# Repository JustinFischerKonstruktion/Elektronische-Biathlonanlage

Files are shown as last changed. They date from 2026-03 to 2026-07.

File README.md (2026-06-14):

# Elektronische Biathlonanlage

## Allgemeines
Das Projekt **"Elektronische Biathlonanlage"** ist ein Umbau für Luftgewehr-Biathlonanlagen. Dieser sorgt dafür, dass die Scheiben nach 5 Treffern oder nach einer eingestellten Zeit ohne Treffer automatisch "gezogen" werden. Zur Datenerfassung werden die einzelnen Treffer zusammen mit der Position innerhalb eines **ESP-NOW Netzwerkes** versendet.

Das System bringt einige Vorteile mit sich: Durch das Fehlen der klassischen Seile der Biathlonanlagen ist kein Auf- und Abwickeln im Training mehr nötig – einfach Strom einschalten und lostrainieren! Auch die Gefahr, dass sich die Seile verknoten oder spannen, wodurch das Fallen der Scheiben verhindert wird, sinkt deutlich. Durch das automatische „Ziehen“ der Anlagen ist ein reibungsloser Ablauf des Trainings möglich. Keiner kann vergessen, die Scheibe zu ziehen, und es kann kein „unvollständiges Ziehen“ geben. Durch das offene System können Trainingsdaten erfasst werden; hier ist für die Zukunft eine Weiterentwicklung mit einer Laufzeitmessung geplant (siehe Zukunftsvision). Durch die zerstörungsfreie Anbringung der 3D-Druckteile geht die Anlage nicht kaputt, die Garantie des Anlagenherstellers wird also nicht verletzt. Die Platine kann sowohl an der Anlage direkt als auch am Stand angebracht werden, somit kann die Anlage flexibel an verschiedenen Standorten eingesetzt werden. Das wasserabweisende und größtenteils auch wasserfeste Design ist auf den Außeneinsatz angepasst.

Der Schützenverein Wolfartsweiler ([sv-wolfartsweiler.de](https://www.sv-wolfartsweiler.de)) hat seit über einem Jahr 8 umgebaute Anlagen im Betrieb. Pro Anlage kostete uns der Umbau ca. 210 €. Pro Anlage kann man mit ca. 2 Arbeitsstunden für die Installation rechnen, zusätzlich zur Installation von Kabeln im Schießstand. Außerdem testet der Schützenverein aktuell einen Prototypen zur autonomen Laufzeiterfassung und Laufzeitauswertung.

Mit dem Wettbewerb NMH Makes Heroes ([nmh-makes-heroes.nmh.de](https://nmh-makes-heroes.nmh.de)) unterstützte mich die Firma NMH ([nmh.de](https://www.nmh.de)) mit einer Fördersumme und technischer Beratung. Während der kurzen Wettbewerbszeit (ca. 6 Wochen) entstand aus einem Prototypen ein fertiges, einsatzfähiges System, welches ich bei allen 8 Anlagen installieren konnte. Vielen Dank an dieser Stelle an NMH!

Wenn Sie mein Projekt interessiert und Sie sich für die Zukunft des Projektes interessieren, können Sie sich gerne die Zukunftsvision anschauen; hier werden mögliche Weiterentwicklungen aufgezeigt. Wenn Sie mich unterstützen wollen, können Sie das gerne über gofundme machen: https://gofund.me/d172d4579 . Sollten Sie Anregungen, Fehler oder Wünsche haben, können Sie hier Issues erstellen oder einfach eine Diskussion starten. Auch auf Instagram können Sie gerne Kontakt zu mir aufnehmen: [@justin_fischer_konstruktion](https://www.instagram.com/justin_fischer_konstruktion/)

## Hardware

Die Automatisierung der Anlage erfolgt mithilfe von Endschaltern und einem **12V DC Motor**, gesteuert von einem **ESP32-D1 mini** auf einer eigens entworfenen Platine. Hier werden die Endschalter so verkabelt, dass die Scheibenposition im Programm (Scheibe 1–5) mit der mechanischen Position übereinstimmt.

Die 3D-gedruckten Komponenten werden zerstörungsfrei an den bestehenden Anlagen angebracht.
**Getestete Anlagen:** Rika und Hora
**Link zu den 3D-Modellen inkl. Druckeinstellungen (MakerWorld):**
*(STEP-Dateien findet ihr hier auf GitHub)*

**Hora:**
* Gesamte Anlage: https://makerworld.com/de/models/2599343-umbau-hora-anlage-gesamt#profileId-2868269
* Motorhalter: https://makerworld.com/de/models/2634566-motorgehause-hora#profileId-2909867
* Endschalterhalter: https://makerworld.com/de/models/2634540-endschalterhalterung-hora#profileId-2909835
* Halter / Halter mit Kabel: https://makerworld.com/de/models/2634652-platinengehausehalter-hora#profileId-2909964

**Rika:**
* Gesamte Anlage: https://makerworld.com/de/models/2634761-umbau-rika-anlage-gesamt#profileId-2910064
* Motorhalter: https://makerworld.com/de/models/2634928-motorgehause-rika#profileId-2910264
* Endschalterhalter: https://makerworld.com/de/models/2634916-endschalterhalterung-rika#profileId-2910247
* Platinenhalter:https://makerworld.com/de/models/2634963-platinenhalterung-rika#profileId-2910308

**Zubehör für beide Typen:**
* Platinenhalter außen: https://makerworld.com/de/models/2635003-platinengehaussehalterung-aussen#profileId-2910358
* Scheibe: https://makerworld.com/de/models/2635039-scheibe#profileId-2910395
* Adapter Platine zu Gehäuse: https://makerworld.com/de/models/2635074-adapter-platine#profileId-2910440

**Update(14.06.26):** Bei der Scheibe wurde eine zusätzliche Fixierung durch eine M3 Schraube vorgesehen.

Zur Einhaltung der Schießstandrichtlinien wurde eine Verkleidung aus Blech an dem Motorhalter angebracht. Diese wurde bei Blexon bestellt. Die entsprechende **STEP-Datei des Blechs** findet ihr ebenfalls hier bei GitHub. Wir haben ein 2 mm Edelstahlblech verwendet, um den Schießstandrichtlinien gerecht zu werden und um Rost und Abnutzung vorzubeugen.

**Blexon Link:** [blexon.com](https://blexon.com)

---

## Verkabelung

Zur Verkabelung der Anlage wurde eine selbst entworfene Platine angefertigt.

<p align="center">
  Verkabelung_Steckplatine
  <br>
  <em style="color: grey;">Abbildung 1: Schaltlogik (unmaßstäblich, erstellt mit Fritzing)</em>
</p>

### Überblick der Verkabelung:

* Alle Endschalter sind über den **COM-Anschluss** mit Ground (GND) verbunden.
* Das Relaismodul wird mit **5V** betrieben und verbindet den Motor über den **Normally Open (NO)** Anschluss mit +12V.
* Der Informationsanschluss des Relaismoduls wird mit **Pin 25** des ESP32 verbunden.
* Der Endschalter beim Motor wird über den **NO-Anschluss** mit **Pin 16** des ESP32 verbunden.

Die Endschalter der Klappen werden über die **NO-Anschlüsse** an folgende Pins angeschlossen:
* Klappe 1: **Pin 23**
* Klappe 2: **Pin 5**
* Klappe 3: **Pin 26**
* Klappe 4: **Pin 18**
* Klappe 5: **Pin 19**

**Meine Platine bei OSHWLab:** https://oshwlab.com/justin.fischer.konstruktion/project_apwkcymk

---

### Der Master

Der Master verfügt über folgende Anbauteile:

**Real time clock (RTC):**
* SCL an **Pin 22**
* SDA an **Pin 21**

**JDY-31 Bluetooth-serielles Modul:**
* RX an **Pin 16**
* TX an **Pin 17**

---

### Stücklisten

#### Stückliste für eine Anlage:

| Bezeichnung | Stückzahl pro Anlage | Link |
| :--- | :---: | :--- |
| **3D-Gedruckte Teile** | | |
| Endschalterhalter (2 Varianten) | 5 | |
| Motorgehäuse | 1 | |
| Scheibe | 1 | |
| Gehäusehalterungen | 1 | |
| Gehäusehalterungen (optional) | (1) | |
| **Zukaufteile** | | |
| Edelstahlbleche | 1 | |
| ESP32 D1 Mini | 1 | [Amazon](https://www.amazon.de/dp/B0DHY5C3Q3) |
| Step Down Converter | 1 | [Amazon](https://www.amazon.de/dp/B0B92ZDK6T) |
| 12V DC Motor | 1 | [Amazon](https://www.amazon.de/dp/B0D9JTQWVB) |
| Platine (optional) | (1) | siehe unten |
| Gehäuse für Platine | (1) | [Amazon](https://www.amazon.de/dp/B0747RGBFF) |
| Endschalter für Motor | 5 | [Amazon](https://www.amazon.de/dp/B0DX27MVWB) |
| Endschalter für Klappen | 1 | [Reichelt](https://www.reichelt.de/de/de/shop/produkt/snap-action-mikroschalter_1x_um_rollenhebel-191380) |
| Kabel (Stromversorgung) | 1 | [Amazon](https://www.amazon.de/dp/B07DPND6NG) |
| Kugellager | 1 | [Amazon](https://www.amazon.de/dp/B0CL4ZN6BV) |
| Schrauben M2x10 | 2 | [Amazon](https://www.amazon.de/dp/B015A3ISUA) |
| Schrauben M2x12 | 10 | [Amazon](https://www.amazon.de/dp/B0DMSP42ZG?ref_=ppx_hzsearch_conn_dt_b_fed_asin_title_6) |
| Schrauben M3x8 | 12 | [Amazon](https://www.amazon.de/dp/B073ZY19VS) |
| Schrauben M3x25 | 2 | [Amazon](https://www.amazon.de/dp/B0DHKQNZ2C?ref_=ppx_hzsearch_conn_dt_b_fed_asin_title_5&th=1) |
| Schrauben M5x10 | 2 | [Amazon](https://www.amazon.de/dp/B015A3ISUA) |
| Selbstschneidende Schrauben | 4 | [Amazon](https://www.amazon.de/dp/B0D9JTQWVB) |
| Einschmelzmutter M3 | 4 (8 für Hora) | [Amazon](https://www.amazon.de/dp/B0CRHMB248) |
| Mutter M3 | 2 (6 für Rika) | bei Schrauben dabei |
| Kabeldurchführungen | 8 | [Amazon](https://www.amazon.de/dp/B0CXPSG55G) |
| Radialwellendichtring (opt.) | (1) | [Amazon](https://www.amazon.de/dp/B0DVJ32JPS) |

#### Stückliste des Masters:

| Bezeichnung | Stückzahl | Link |
| :--- | :---: | :--- |
| ESP32 D1 Mini | 1 | [Amazon](https://www.amazon.de/dp/B0DHY5C3Q3) |
| Bluetooth Modul | 1 | [Amazon](https://www.amazon.de/dp/B0FFZ43YCC) |
| Real time Clock Modul | 1 | [Amazon](https://www.amazon.de/dp/B01H5NAFUY) |
| Gehäuse für ESP32 | (1) | [Amazon](https://www.amazon.de/dp/B0747RGBFF) |
| Lötplatine | (1) | [Amazon](https://www.amazon.de/dp/B07DK2S1XG) |

**Sonstige Zukaufteile:**
* Kabel: [Amazon](https://www.amazon.de/dp/B07DK2S1XG)
* Verteilerdosen: [Amazon](https://www.amazon.de/dp/B09D3XP1Z1)
* Solarmodul inkl. Akku: [Amazon](https://www.amazon.de/dp/B09D3XP1Z1)
* 12V-Netzteil: [Amazon](https://www.amazon.de/dp/B07GFFG1BQ)
* DC-Backup Schaltmodul: [Amazon](https://www.amazon.de/dp/B07B4D73K9)
* Dichtungsstreifen: [Amazon](https://www.amazon.de/dp/B0CWNCHX7T)

---

## Software

Die Software der Anlagen sowie des Masters wurde mit der **Arduino IDE** geschrieben. Ihr findet die `.ino`-Dateien zum Download im Ordner `Software`.

Bei Inbetriebnahme müsst ihr die MAC-Adresse eures Masters herausfinden und notieren. In den Skripten der Anlagen müssen folgende drei Variablen ganz oben im Code angepasst werden:

1. **Anlage:** Die Nummer eurer Anlage (von oben nach unten, dann von links nach rechts). Beispiel: Stehende Anlage links = Nr. 1; liegende Anlage = Nr. 2; zweite stehende Anlage von links = Nr. 3 usw.
2. **uint8_t receiverAddress[]:** Die MAC-Adresse eures Masters.
3. **Variable `zeit`:** Hier wird die Zeit eingestellt, nach der die Anlage automatisch zieht. Standardmäßig nutzen wir für liegende Anlagen 10 Sekunden (`zeit=10000`) und für stehende Anlagen 20 Sekunden (`zeit=20000`). Die Angabe erfolgt in Millisekunden.

### Handy-App

Hier auf GitHub findet ihr im Ordner `Software` die Biathlon-App sowohl als APK zum Installieren auf Android-Handys als auch die AIA-Datei zum Öffnen in App Inventor für die Anpassung an eure Bedürfnisse. Hierfür braucht ihr einen Account beim MIT App Inventor.
App Inventor: [appinventor.mit.edu](https://appinventor.mit.edu)

<p align="center">
  App Startseite
  <br>
  <em style="color: grey;">Abbildung 2: Handy App Startseite</em>
</p>

Auf der Startseite der App könnt ihr links oben die Seiten wechseln. Mit dem Button links neben der Mitte könnt ihr verfügbare Bluetooth-Geräte abfragen und euch verbinden. Danach werden euch die Treffer der Anlagen angezeigt. Mit den Schiebereglern wechselt ihr den Modus, mit den Reset-Knöpfen löst ihr den Ziehvorgang manuell aus (für alle Anlagen gleichzeitig oder einzeln).

<p align="center">
  App Einstellungen
  <br>
  <em style="color: grey;">Abbildung 3: Handy App Einstellungsseite</em>
</p>

Auf der Einstellungsseite könnt ihr eigene Zeiten für die Modi eingeben und per Senden-Button an den Master übertragen.

<p align="center">
  App Ergebnisse
  <br>
  <em style="color: grey;">Abbildung 4: Handy App Ergebnisseite</em>
</p>

Hier könnt ihr eine Liste der letzten Ergebnisse abfragen. Da die Übertragung via Bluetooth Zeit benötigt, ist diese Funktion bei begrenzter Leistung nicht immer zu 100 % zuverlässig.

---

## Netzwerk

<p align="center">
  Netzwerkaufbau
  <br>
  <em style="color: grey;">Abbildung 5: Netzwerkaufbau (erstellt mit Inkscape)</em>
</p>

Das Netzwerk besteht aus einem Master und bis zu 20 Slaves (bedingt durch die ESP-NOW Einschränkung). Die Anlagen fungieren als Slaves, der Master als eigenständige Zentrale. Wir haben unseren Master aktuell in der Nähe der Schützen platziert; der Abstand zu den Anlagen beträgt 10 m. Auf diese Distanz haben wir die Anlagen getestet und bisher keine Probleme festgestellt.

Folgende Variablen werden intern für Befehle und Daten genutzt:
* `hits`: Anzahl der Treffer
* `position`: Position des Treffers 1–5 (6 für Reset der Anzeige)
* `Anlage`: Nummer der sendenden Anlage
* `reset`: 0–n (Nummer der zu ziehenden Anlage; 0 = alle)
* `target`: 0–n (Wechsel in den Target-Modus; 0 = alle)
* `normal`: 0–n (Wechsel in den Magazin-Modus; 0 = alle)
* `customtarget`: Eigene Zeiteinstellung für den Targetmodus (in Sekunden)
* `customnormal`: Eigene Zeiteinstellung für den Magazinmodus (in Sekunden)

Wir haben das Netzwerk erfolgreich mit einem Master und 8 Slaves getestet und sind sehr zufrieden. Der Master verbindet sich per Bluetooth mit dem Handy; Daten und Befehle werden im Textformat gesendet und von der Android-App (erstellt mit **MIT App Inventor**) verarbeitet.

---

## Referenzen

Video, das die aktuellen Probleme von Seilzuganlagen aufzeigt:
<p align="center">
  <a href="https://youtu.be/Kdan_EM31K0">
    Video Thumbnail
    <br>
  <b>Video: Probleme der aktuellen Seilzuganlagen</b>
  </a>
<p align="center">
  <a href="https://youtu.be/Kdan_EM31K0](https://youtu.be/JK2AczdJDU0">
    
    <br>
  <b>Video: Trailer Projekt</b>
  </a>
</p>












## Haftungsausschluss (Disclaimer)

**Die Nutzung dieser Anleitung, der Software und der Hardware-Designs erfolgt auf eigene Gefahr.**

* **Keine Garantie:** Dieses Projekt wird "wie besehen" (as-is) zur Verfügung gestellt. Ich übernehme keine Garantie für die Funktion, Vollständigkeit oder Richtigkeit der bereitgestellten Informationen.
* **Haftungsausschluss:** Ich hafte nicht für Schäden an Hardware (z. B. Kurzschlüsse, defekte Motoren), Verletzungen oder sonstige Folgeschäden, die durch den Nachbau oder Betrieb dieser Anlage entstehen.
* **Eigenverantwortung:** Der Nutzer ist selbst dafür verantwortlich, dass der Umbau den geltenden Sicherheitsregeln und Schießstandrichtlinien entspricht.

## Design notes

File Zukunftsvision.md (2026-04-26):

# Zukunftsvision – Die Elektronische Biathlonanlage 2.0

Im Verein nutzen wir aktuell seit knapp einem Jahr acht aufgerüstete Biathlonanlagen und sind sehr zufrieden. Daher erfolgt nun auch die Veröffentlichung als Open-Source-Projekt.

Der aktuelle Aufbau ist jedoch recht zeitintensiv (ca. 2 Stunden pro Anlage) und benötigt Fachkenntnisse im Löten, Programmieren und 3D-Drucken. Nicht jeder Verein hat jemanden, der diese Fähigkeiten besitzt und gewillt ist, die Zeit dafür zu opfern. Daher möchte ich den Umbausatz zu einem echten „Plug-and-Play“-System weiterentwickeln.

#### Geplante Hardware-Änderungen:
* **Steckverbindungen:** Umstieg auf genormte Kabel mit M8- oder M12-Schraubverbindungen.
* **Sensorik:** Umstieg auf Induktivsensoren für die Treffererfassung (ebenfalls mit Standard-M12-Verbindung).
* **Antrieb:** Umstieg auf Servomotoren, um zusätzliche Endschalter zu vermeiden.
* **Platinen-Design:** * Eigene Platine speziell für Sensoren.
    * Neue Steuerplatine.
    * Neue Platine für die Stromversorgung mit Schaltlogik für den kombinierten Betrieb von Solar und Netzteil.
* **Kommunikation:** Anschluss eines M8- oder M12-Ethernet-Kabels ermöglichen, um eine reibungslose Kommunikation auch bei vielen Anlagen zu gewährleisten.
* **Mechanik:** Neue Halterungen für Sensoren, Platinen und Motoren sowie die Anpassung an weitere Anlagentypen.
* **Fertigung:** 3D-Druckteile per Link bestellbar machen (für Vereine ohne eigenen 3D-Drucker).

#### Begleitende Inhalte:
* YouTube-Tutorials für den Aufbau, die Software-Installation und die Bedienung der App.
* Eine YouTube-Entscheidungshilfe für interessierte Vereine.
* Eventuell eine eigene Projektwebsite sowie ein Discord-Kanal zur direkten Kommunikation.

### Kosten der Weiterentwicklung
Diese Entwicklung benötigt Zeit und finanziellen Einsatz. Die geplanten Entwicklungskosten belaufen sich auf:

| Teil | Preis |
| :--- | ---: |
| Testanlage leihen/kaufen | 350,00 € |
| Neue Steuerplatine | 25,00 € |
| Neue Sensorplatine | 30,00 € |
| Neue Stromverteilungsplatine | 20,00 € |
| Servomotor | 20,00 € |
| Induktivsensoren (5 Stück) | 70,00 € |
| 3D-Druckteile (Zukauf testen) | 120,00 € |
| Filament (Testdrucke) | 40,00 € |
| Kabel und Schrauben | 50,00 € |
| Netzgerät | 15,00 € |
| ESP32 D1 Mini (2x) | 30,00 € |
| Sonstige Teile | 30,00 € |
| **Gesamt** | **800,00 €** |

Ziel ist eine Plug-and-Play-Lösung, die einfach und schnell installiert werden kann. Die Kosten pro Umbausatz werden sich schätzungsweise auf ca. 250 € bis 350 € belaufen (abhängig von Stückzahl und Ausführung).

### Laufzeiterfassung
Aktuell arbeite ich zudem an einem Prototypen zur Laufzeiterfassung. Dieser ist momentan über ein einfaches NFC-Zeitnahmesystem umgesetzt, soll aber in naher Zukunft auf Kameratechnik umgestellt werden. Mithilfe von Google Sheets und App Script werden die Daten erfasst, sortiert und für jeden Athleten eine individuelle Übersicht erstellt. Da der erste Prototyp derzeit ausgiebig getestet wird, gibt es hier noch keine konkreten Kostenpläne; die Schätzung für das Gesamtsystem liegt bei ca. 500 €.

Sollten Ihnen diese Ideen gefallen, können Sie mich gerne bei der Umsetzung unterstützen. Bei gofundme sammle ich die 800€ für die Weiterentwicklung: https://gofund.me/d172d4579

Vielen Dank für Ihr Interesse und Ihre Unterstützung!

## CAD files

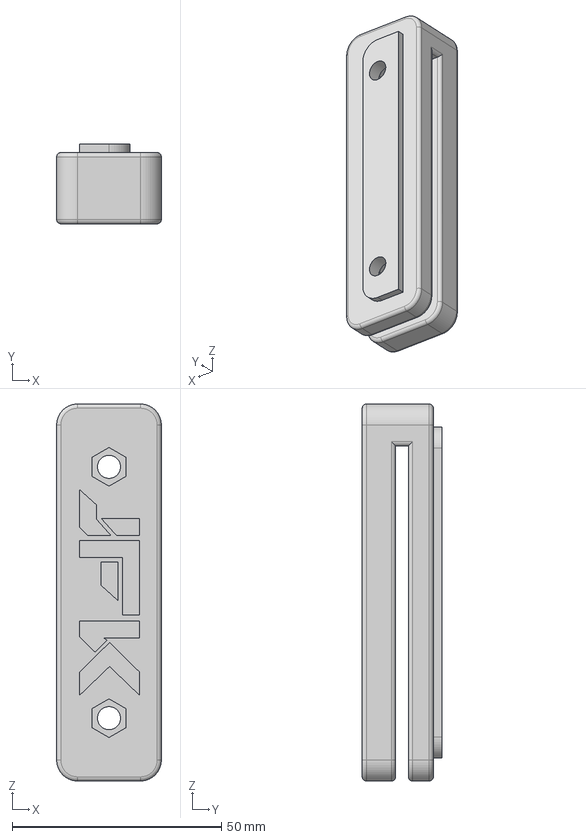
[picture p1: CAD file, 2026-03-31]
3D-Dateien/Hora/Halter Anlage 1.step
25.0 x 19.0 x 90.0 mm

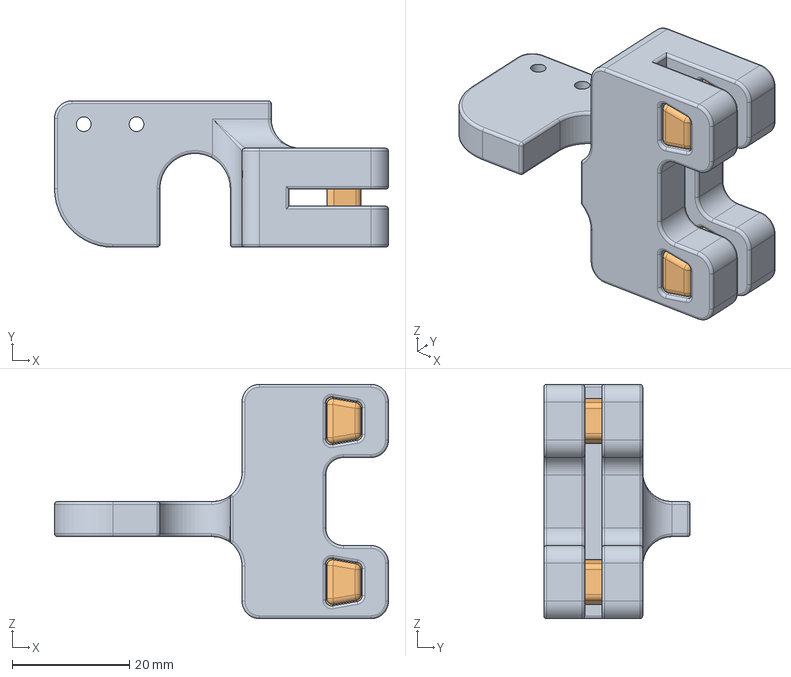
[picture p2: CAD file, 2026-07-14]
3D-Dateien/Rika/Endschalter mit Rolle.step
57.0 x 25.0 x 40.0 mm

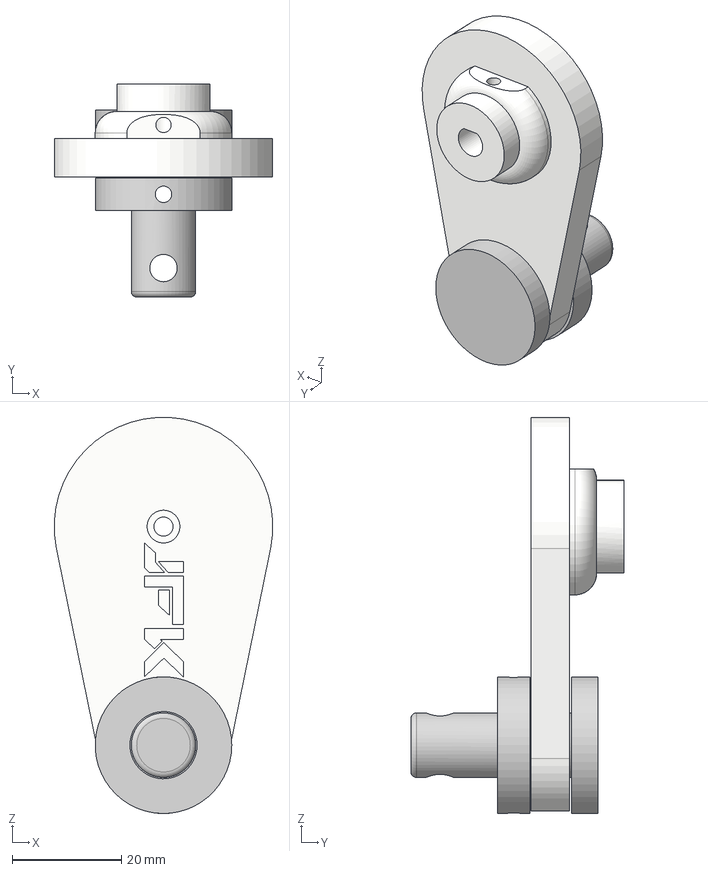
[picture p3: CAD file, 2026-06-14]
3D-Dateien/Zubehör für alle Typen/Scheibe neu.step
40.0 x 39.0 x 72.5 mm
Komponente1
Komponente2
Komponente4

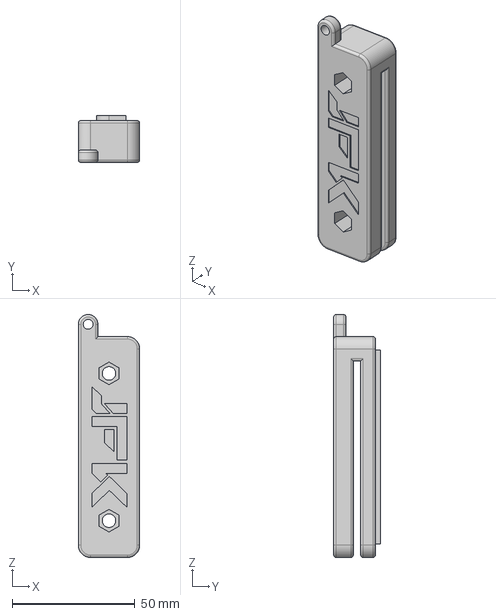
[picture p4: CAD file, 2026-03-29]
3D-Dateien/Hora/Halter Anlage 1mit kabel.step
25.0 x 19.0 x 99.0 mm

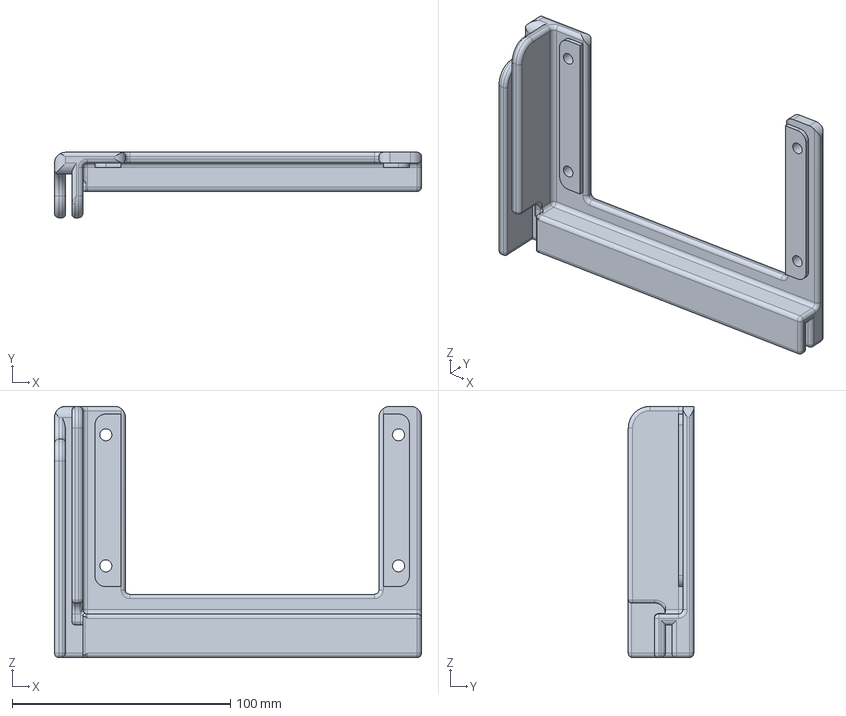
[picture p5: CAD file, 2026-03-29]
3D-Dateien/Rika/Halter Platine.step
168.0 x 30.0 x 115.0 mm

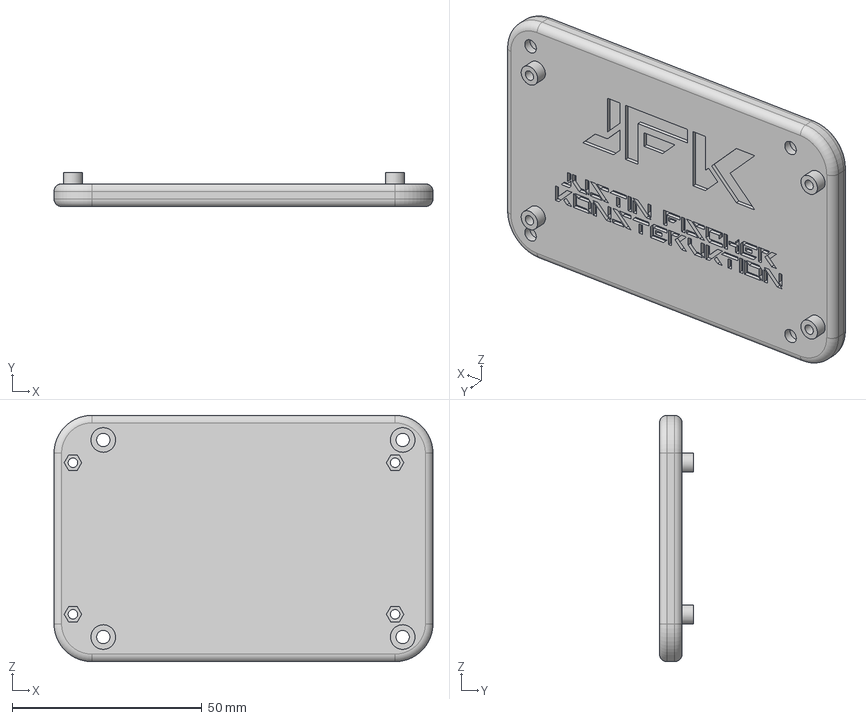
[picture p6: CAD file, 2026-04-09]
3D-Dateien/Zubehör für alle Typen/Adapter Platine v8.step
100.0 x 9.00 x 65.0 mm

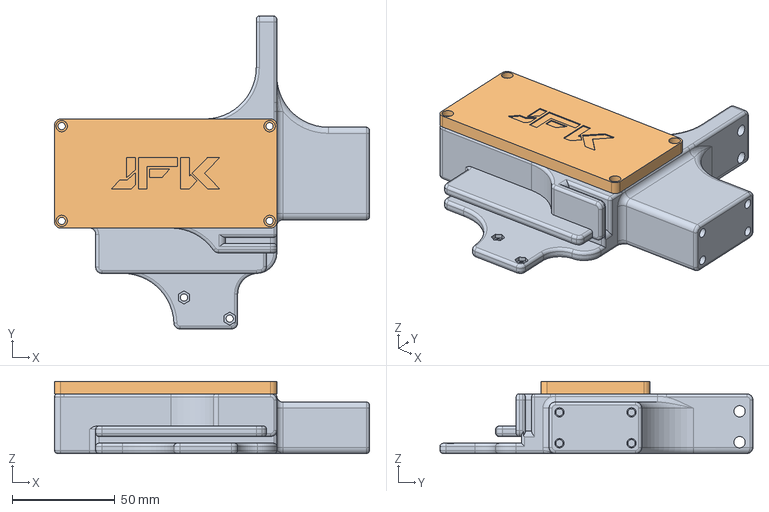
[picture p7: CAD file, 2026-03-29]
3D-Dateien/Hora/Motorgehäuse.step
153.0 x 152.0 x 35.0 mm

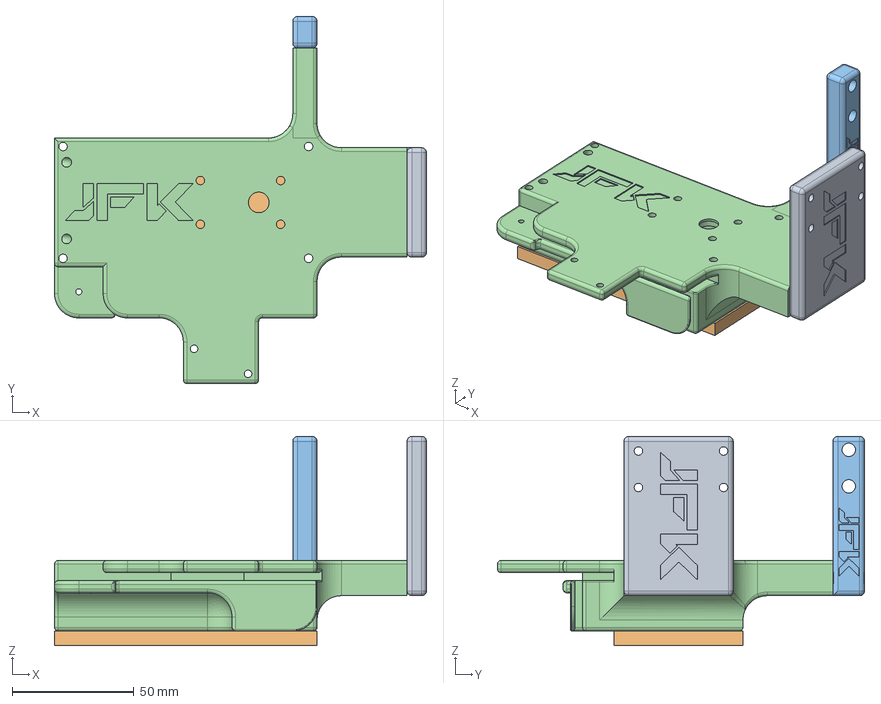
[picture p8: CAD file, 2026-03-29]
3D-Dateien/Rika/Motorgehäuse.step
153.0 x 151.0 x 86.0 mm

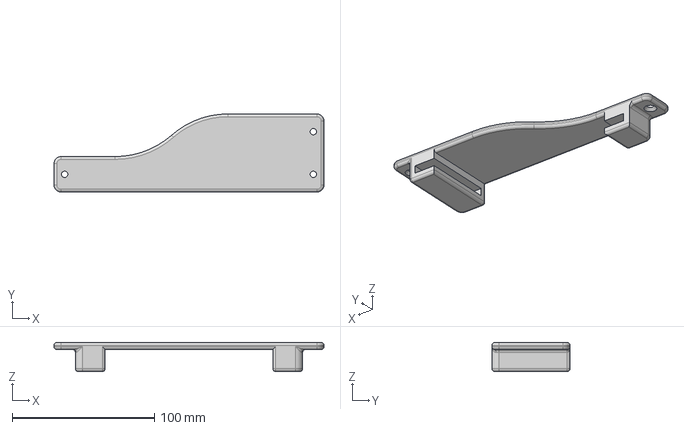
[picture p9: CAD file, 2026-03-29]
3D-Dateien/Zubehör für alle Typen/Halter Platine außen.step
190.0 x 55.0 x 20.5 mm

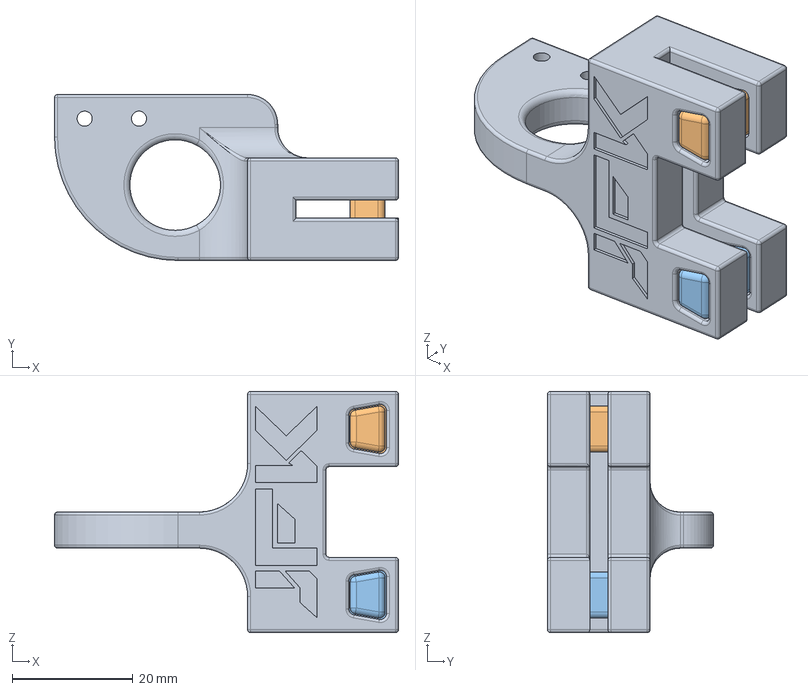
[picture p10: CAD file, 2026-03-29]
3D-Dateien/Hora/Endschalter Panasonic Halterung.step
57.0 x 27.5 x 40.0 mm

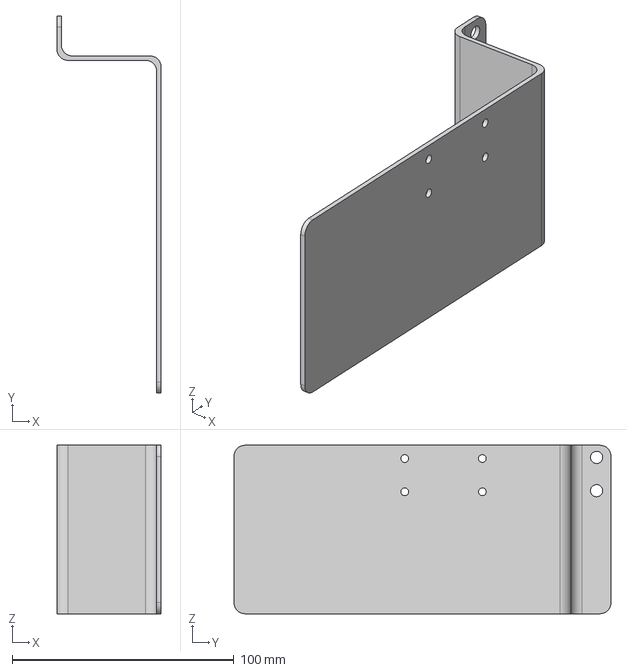
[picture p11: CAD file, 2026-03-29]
3D-Dateien/Zubehör für alle Typen/Blech.step
47.0 x 170.0 x 76.0 mm

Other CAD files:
3D-Dateien/Rika/Endschalter mit Rolle.stl

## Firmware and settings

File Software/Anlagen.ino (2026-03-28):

#include <esp_now.h>
#include <WiFi.h>

// Variablen definieren
int anlage = 1;      //Nummer der Anlage      
int zeit = 20000;    //Standardzeit in ms 10sek. für Normal 20sek. für Target     
//Anschlüsse der Komponenten
int motor = 25;            
int endPin = 16;           
int sensor[5] = { 23, 5, 26, 18, 19 }; 

// Variablen für die Logik
byte sensorflag[5] = { 0, 0, 0, 0, 0 };    
byte lastsensorstate[5] = { 1, 1, 1, 1, 1 }; 
unsigned long startzeit = 0;               
int start = 0;                             

uint8_t receiverAddress[] = { 0x5c, 0x01, 0x3b, 0x87, 0x4f, 0x08 };  //Adresse für den Master FF überall sendet an alle
// uint8_t receiverAddress[] = { 0xFF, 0xFF, 0xFF, 0xFF, 0xFF, 0xFF }; //Nur für Testzwecke
// Mac Adresse des Masters: 5c:01:3b:87:4f:08

esp_now_peer_info_t peerInfo;

//Alle Variablen zum senden
typedef struct messageToBeSent {
    int hits = 0;     
    int anlage;       
    int position;     
    char ergebnis[32]; 
} messageToBeSent;

//Alle Variablen zum Empfangen
typedef struct receivedMessage {
    int online = 0;   
    int customtarget = 10000;
    int customnormal = 20000; 
    int reset = 666;  
    int target = 666;
    int normal = 666;
} receivedMessage;

messageToBeSent myMessageToBeSent; 
receivedMessage myReceivedMessage; 

//Erstellen des Trefferbilds
void erstelleErgebnisString() {
    String visual = "";
    for (int i = 0; i < 5; i++) {
        visual += (sensorflag[i] == 1) ? "○" : "●";
    }
    visual.toCharArray(myMessageToBeSent.ergebnis, 32);
}

void messageReceived(const esp_now_recv_info_t *info, const uint8_t* incomingData, int len) {
    memcpy(&myReceivedMessage, incomingData, sizeof(myReceivedMessage));
}

void messageSent(const wifi_tx_info_t *tx_info, esp_now_send_status_t status) {}

//Reset Funktion
void goal() {
    digitalWrite(motor, HIGH); 

    if (digitalRead(endPin) == LOW) {
        delay(150); 
        digitalWrite(motor, LOW); 
        delay(300); 

        // 1. Abschluss-Paket senden
        myMessageToBeSent.anlage = anlage;
        erstelleErgebnisString();
        myMessageToBeSent.position = 6; 
        esp_now_send(receiverAddress, (uint8_t *) &myMessageToBeSent, sizeof(myMessageToBeSent));
        
        // 2. Variablen für die nächste Runde zurücksetzen
        for (int i = 0; i < 5; i++) {
            sensorflag[i] = 0;
            lastsensorstate[i] = 1;
        }
        
        myMessageToBeSent.hits = 0;    
        myMessageToBeSent.position = 0; 
        myMessageToBeSent.anlage = anlage; //zur Sicherheit
        startzeit = 0;
        start = 1; 

        // 3. Reset-Paket senden
        erstelleErgebnisString();
        esp_now_send(receiverAddress, (uint8_t *) &myMessageToBeSent, sizeof(myMessageToBeSent));
    }
}

//Vorbereitungen treffen
void setup() {
    Serial.begin(115200);
    WiFi.mode(WIFI_STA);
    WiFi.disconnect(); 

    if (esp_now_init() != ESP_OK) return;

    esp_now_register_send_cb(messageSent);
    esp_now_register_recv_cb(messageReceived);

    memcpy(peerInfo.peer_addr, receiverAddress, 6);
    peerInfo.channel = 0;  
    peerInfo.encrypt = false;
    esp_now_add_peer(&peerInfo);

    pinMode(motor, OUTPUT);
    pinMode(endPin, INPUT_PULLUP);
    for (int i = 0; i < 5; i++) pinMode(sensor[i], INPUT_PULLUP);
    
    myMessageToBeSent.anlage = anlage; 
    Serial.println("System bereit.");
}

void loop() {
    // Falls ein Paket von außen anlage auf 0 setzt, hier im Loop immer wieder erzwingen:
    myMessageToBeSent.anlage = anlage;
    //Onlineabfrage
    if (myReceivedMessage.online == 1) {  
        myMessageToBeSent.anlage = anlage; 
        esp_now_send(receiverAddress, (uint8_t *) &myMessageToBeSent, sizeof(myMessageToBeSent));
        myReceivedMessage.online = 0;
    }
    //Reset starten
    if (start == 0) goal();
    //manueller Reset verarbeiten
    if (myReceivedMessage.reset == 0 || myReceivedMessage.reset == anlage) {
        start =0;
        myReceivedMessage.reset = 666; 
    }
    //Targetmodus
    if (myReceivedMessage.target == 0 || myReceivedMessage.target == anlage){
        zeit = myReceivedMessage.customtarget;
    }
    //Normaler Modus
    if (myReceivedMessage.normal == 0 || myReceivedMessage.normal == anlage){
        zeit = myReceivedMessage.customnormal;
    }

    //prüft ob ein Endschalter ausgelöst wurde und setzt die passende Flag und sendet alle Informationen zum Master
    for (int i = 0; i < 5; i++) {
        int reading = digitalRead(sensor[i]);
        if (reading == LOW && lastsensorstate[i] == HIGH) {
            delay(20); 
            if (digitalRead(sensor[i]) == LOW && sensorflag[i] == 0) {
                sensorflag[i] = 1; 
                if (startzeit == 0) startzeit = millis();
                
                myMessageToBeSent.hits++; 
                myMessageToBeSent.position = i + 1;
                myMessageToBeSent.anlage = anlage;
                erstelleErgebnisString();
                esp_now_send(receiverAddress, (uint8_t *) &myMessageToBeSent, sizeof(myMessageToBeSent));
            }
        }
        lastsensorstate[i] = reading;
    }
    //startet den Reset wenn 5 treffer erzielt sind oder die Zeit abgelaufen ist
    if (myMessageToBeSent.hits == 5 || (startzeit > 0 && millis() > (startzeit + zeit))) { 
        goal();
    }
}

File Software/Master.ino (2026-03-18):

#include <WiFi.h>
#include <esp_now.h>
#include <Preferences.h>
#include <Wire.h>
#include "RTClib.h"

//Bluetooth Modul und Real Time Clock Modul
HardwareSerial SerialBT(2); // Bluetooth an Pins 16 (RX), 17 (TX)
RTC_DS3231 rtc;
Preferences preferences;

//ausgehende Variablen
typedef struct { 
    int online; 
    int customtarget; 
    int customnormal; 
    int reset; 
    int target; 
    int normal; 
} msgSent;

//Eingehende Variablen
typedef struct { 
    int hits; 
    int anlage; 
    int position; 
    char ergebnis[32]; 
} msgRecv;

//Eintragung für Ergebnissliste
struct ScoreEntry { 
    int anlage; 
    int hits; 
    uint32_t timestamp; 
    char muster[32]; 
};

ScoreEntry scoreList[100];
int currentEntryIndex = 0;
msgSent myMessageToBeSent = {0, 10000, 20000, 666, 666, 666};
msgRecv myReceivedMessage;
uint8_t receiverAddress[] = { 0xFF, 0xFF, 0xFF, 0xFF, 0xFF, 0xFF }; //Senden an alle im ESP NOW Netzwerk Broadcast Addresse

//Daten empfangen
void messageReceived(const esp_now_recv_info_t *info, const uint8_t *incomingData, int len) {
    memcpy(&myReceivedMessage, incomingData, sizeof(myReceivedMessage));

    esp_now_send(receiverAddress, (uint8_t *)&myMessageToBeSent, sizeof(myMessageToBeSent));

    //Live Rückmeldung für die Anzeige in der App
    String live = "a" + String(myReceivedMessage.anlage) + "p" + String(myReceivedMessage.position) + 
                  "h" + String(myReceivedMessage.hits) + "m" + String(myReceivedMessage.ergebnis);
    SerialBT.println(live);

    //Speichern bei position 6 (reset)
    if (myReceivedMessage.position == 6) {
        DateTime now = rtc.now();
        scoreList[currentEntryIndex].anlage = myReceivedMessage.anlage;
        scoreList[currentEntryIndex].hits = myReceivedMessage.hits;
        scoreList[currentEntryIndex].timestamp = (uint32_t)now.unixtime();
        strncpy(scoreList[currentEntryIndex].muster, myReceivedMessage.ergebnis, 31);
        
        currentEntryIndex = (currentEntryIndex + 1) % 100;
        preferences.putBytes("score_list", scoreList, sizeof(scoreList));
        preferences.putInt("score_idx", currentEntryIndex);
    }
}

// Ergebnisliste an App senden
void sendeTextListe() {
    SerialBT.println("SYNC_START"); //startmarkierung
    delay(300); 
    //Aufbau der Liste
    for (int i = 0; i < 100; i++) {
        int idx = (currentEntryIndex - 1 - i + 100) % 100;
        if (scoreList[idx].timestamp > 1000000) { 
            DateTime dt(scoreList[idx].timestamp);
            char buffer[120];
            sprintf(buffer, "%02d.%02d.%04d %02d:%02d | Anlage: %d | Treffer: %d | %s", 
                    dt.day(), dt.month(), dt.year(), dt.hour(), dt.minute(), 
                    scoreList[idx].anlage, scoreList[idx].hits, scoreList[idx].muster);
            SerialBT.println(buffer);
            delay(150); 
        }
    }
    delay(300);
    SerialBT.println("SYNC_ENDE");//Endmarkierung
}

void setup() {
    Serial.begin(115200);
    SerialBT.begin(9600, SERIAL_8N1, 16, 17); 
    Wire.begin(21, 22);

    // RTC initialisieren & Zeit prüfen
    if (!rtc.begin()) Serial.println("RTC nicht gefunden!");
    if (rtc.lostPower()) {
        Serial.println("RTC Zeit-Fix angewendet");
        rtc.adjust(DateTime(F(__DATE__), F(__TIME__)));
    }

    // ESP-NOW Setup
    WiFi.mode(WIFI_STA);
    if (esp_now_init() != ESP_OK) return;
    esp_now_register_recv_cb(messageReceived);
    
    esp_now_peer_info_t peerInfo = {};
    memcpy(peerInfo.peer_addr, receiverAddress, 6);
    peerInfo.channel = 0; peerInfo.encrypt = false;
    esp_now_add_peer(&peerInfo);

    // Datenbank laden
    preferences.begin("schuss_db", false); 
    preferences.getBytes("score_list", scoreList, sizeof(scoreList));
    currentEntryIndex = preferences.getInt("score_idx", 0);
}

// Bluetooth Befehle empfangen.
void loop() {
    if (SerialBT.available()) {
        String msg = SerialBT.readStringUntil('\n');
        msg.trim();
        
        if (msg == "Sync") {
            sendeTextListe();
        }
        else if (msg == "Listelöschen") {
            memset(scoreList, 0, sizeof(scoreList));
            currentEntryIndex = 0;
            preferences.putBytes("score_list", scoreList, sizeof(scoreList));
            preferences.putInt("score_idx", 0);
            Serial.println("!!! DATENBANK GELÖSCHT !!!");
            SerialBT.println("Liste wurde gelöscht");
        }
        else if (msg.startsWith("reset")) {
            myMessageToBeSent.reset = msg.substring(5).toInt();
            esp_now_send(receiverAddress, (uint8_t *)&myMessageToBeSent, sizeof(myMessageToBeSent));
            myMessageToBeSent.reset = 666;
        }
        else if (msg.startsWith("target")) {
            myMessageToBeSent.target = msg.substring(6).toInt();
            esp_now_send(receiverAddress, (uint8_t *)&myMessageToBeSent, sizeof(myMessageToBeSent));
            myMessageToBeSent.target = 666;
        }
        else if (msg.startsWith("normal")) {
            myMessageToBeSent.normal = msg.substring(6).toInt();
            esp_now_send(receiverAddress, (uint8_t *)&myMessageToBeSent, sizeof(myMessageToBeSent));
            myMessageToBeSent.normal = 666;
        }
        else if (msg.startsWith("online")) {
            myMessageToBeSent.online = msg.substring(6).toInt();
            esp_now_send(receiverAddress, (uint8_t *)&myMessageToBeSent, sizeof(myMessageToBeSent));
            myMessageToBeSent.online = 0;
        }
        else if (msg.startsWith("customtarget")) {
            myMessageToBeSent.customtarget = msg.substring(12).toInt();
        }
        else if (msg.startsWith("customnormal")) {
            myMessageToBeSent.customnormal = msg.substring(12).toInt();
        }
    }
}

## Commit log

2026-06-14 Update Scheibe
    [Scheibe neu.step]
2026-06-14 Update Scheibe.md
    Die 3d-Datei der Scheibe wurde ausgetauscht, ein Hinweis im Readme hinzugefügt.
